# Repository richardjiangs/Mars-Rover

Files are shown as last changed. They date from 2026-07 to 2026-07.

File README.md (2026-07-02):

# PROJECT ARES — 低成本火星车原型 (Operation MROS)

一辆 150 美元以内的六轮火星车模型：`ESP32 NodeMCU + ESP32-CAM` 双脑架构、`Rocker-Bogie` 摇臂-转向架悬挂、3D 打印四层主舱、可承受 2 米跌落，能自动驾驶、拍 360° 全景与伪 3D 照片、绘制区域地图，并支持电脑端实时监控与人工接管。

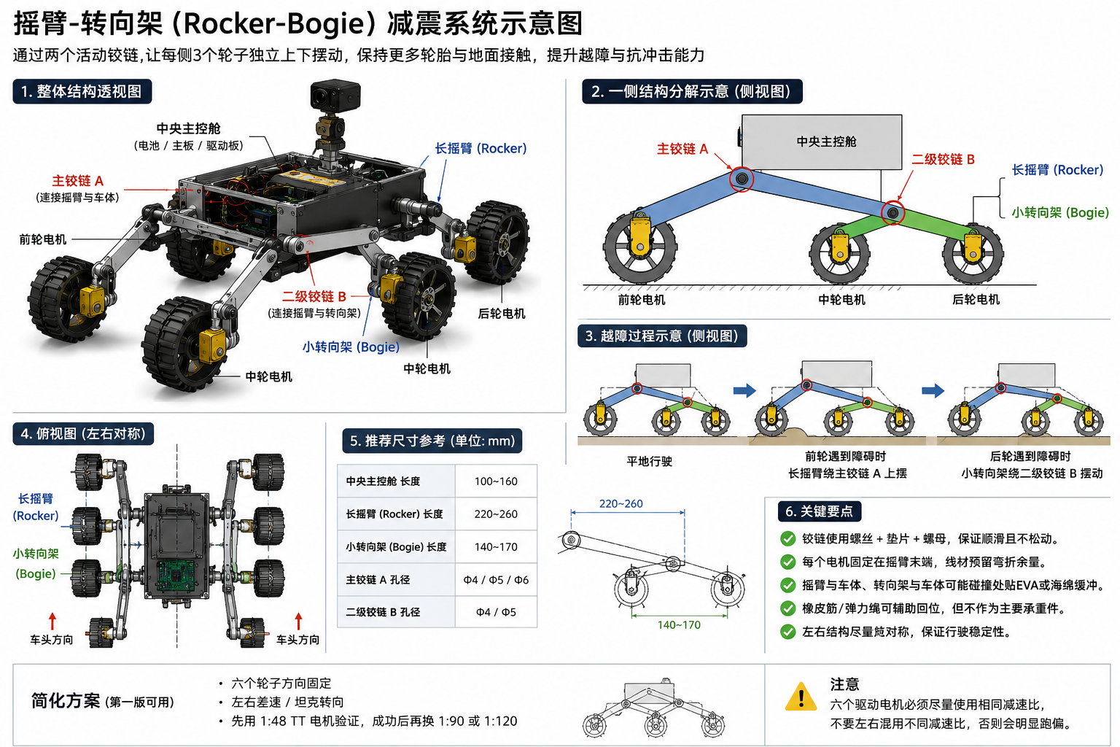
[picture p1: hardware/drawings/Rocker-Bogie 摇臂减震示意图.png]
Rocker-Bogie 示意


## 当前状态

- ✅ 设计定稿（V3 基线：见 `AGENTS.md` 与 `docs/Ares_V3_决策记录.md`）
- ✅ 硬件已采购（`hardware/drawings/部件.jpg`）、结构件已建模（`hardware/cad/`）
- ✅ 固件、网页控制台、电脑端图像处理脚本已编写
- ⏳ 待完成：3D 打印、补采购、装配、烧录、标定与验收测试 → 见 `docs/下一步你要做什么.md`

## 目录导航

| 目录 | 内容 |
| --- | --- |
| `docs/` | 设计文档、决策记录、装配与测试指南、行动清单 |
| `hardware/` | 引脚表（★`Ares_V3_GPIO_Map.md`）、BOM、接线资料、手绘图纸、STL |
| `firmware/commander/` | 主控 ESP32 固件（Arduino IDE 工程） |
| `firmware/cam/` | ESP32-CAM 固件（Arduino IDE 工程） |
| `dashboard/` | 网页控制台（浏览器直接打开 `index.html`） |
| `vision/` | 电脑端 Python：收图服务、全景拼接、红蓝 3D、地图、遥测记录、模拟器 |

## 三条上手路径

**① 我想了解设计** → 依次读 `AGENTS.md` → `docs/楼层布局.md` → `hardware/drawings/总体设计.jpg` → `docs/Ares_Control_Architecture.md`。

**② 我要造车** → 按 `docs/下一步你要做什么.md` 打印/采购/装配，装配细节见 `docs/装配与测试指南.md`，接线唯一以 `hardware/Ares_V3_GPIO_Map.md` 为准。

**③ 我要跑软件（可以完全不接硬件先试）**

```bash
# 1. 安装电脑端依赖
cd vision && pip install -r requirements.txt

# 2. 启动"假火星车"模拟器
python mock_rover.py

# 3. 浏览器打开 dashboard/index.html，
#    车辆地址填 127.0.0.1 后点"连接"，即可看到遥测并用 WASD 遥控
```

有硬件后：按 `firmware/commander/README.md` 与 `firmware/cam/README.md` 烧录两块板，dashboard 里把地址换成火星车真实 IP。

## 安全提醒

18650 电池必须经 2S BMS，充电只用 2S 专用充电器；HC-SR04 的 Echo 引脚需 1k/2k 分压后再接 ESP32；调试电机先把车架空。完整底线见 `AGENTS.md` 的"安全与工程底线"。

## License

Apache-2.0（见 `LICENSE`）。

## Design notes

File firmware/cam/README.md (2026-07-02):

# ESP32-CAM 视觉从板固件（AI-Thinker）

拍照 → HTTP 上传到电脑 `vision/receive_server.py`；提供 `/stream` MJPEG 实时流给 dashboard；通过串口应答 Commander 的拍照命令。协议见 `docs/Ares_Control_Architecture.md` §11.2。

**无需安装第三方库**（相机驱动、WebServer、HTTPClient 都在 ESP32 核心包里）。

## 烧录（用你买的下载器底板最省事）

1. 把 ESP32-CAM 插到 **下载器底板** 上，USB 连电脑。
   （没有底板的话：用 USB-TTL，5V/GND/U0R↔TX/U0T↔RX，且把 `GPIO0 接 GND` 进入烧录模式。）
2. ⚠ **如果板子已装上车：先断开与 Commander GPIO25/23 相连的两根串口线**，否则烧录会失败。
3. Arduino IDE 打开本目录（`cam.ino`），改 `config.h`：
   - `WIFI_SSID / WIFI_PASSWORD`：与 Commander 同一网络；
   - `PC_HOST`：电脑在该网络中的 IP（Windows 移动热点通常是 `192.168.137.1`）。
4. 开发板选 **AI Thinker ESP32-CAM**，点上传。
   （若列表里没有，选 ESP32 Dev Module 并把 PSRAM 设为 Enabled 也可。）
5. 上传完 **把 GPIO0 从 GND 断开**（用底板则拨开关/直接拔插），按 RST 重启。

## 自检

1. 串口监视器（115200）看 `# ip 192.168.x.x` —— 这是相机 IP。
2. 浏览器开 `http://<相机IP>/stream` 应看到实时画面。
3. 电脑先跑 `python vision/receive_server.py`，再访问 `http://<相机IP>/capture?name=test`，
   `vision/incoming/test.jpg` 出现即链路全通。
4. 装上车接回串口线后，Commander 遥测里 `cam` 字段应变为 `READY`。

## 板载指示灯

- 红色小灯（GPIO33）：常亮=启动中，闪烁=连 Wi-Fi，灭=就绪。
- 白色大灯（GPIO4）：默认不用；`config.h` 里 `USE_FLASH_LED 1` 可作拍照补光（耗电）。

## 已知限制

- 与 Commander 的链路复用烧录串口 U0：调试输出以 `# ` 开头，Commander 会忽略；但**烧录/看串口时必须断开车内串口线**。
- MJPEG 直播和拍照上传共用同一颗摄像头，直播中拍照会让画面停顿约 1 秒，正常现象。

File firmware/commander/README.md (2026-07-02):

# Commander 主控固件（ESP32 NodeMCU）

主控板固件：电机差速、直线保持、三向避障、模式状态机、休眠模拟、指挥相机板、WebSocket 遥测遥控。引脚与 `hardware/Ares_V3_GPIO_Map.md` 一致。

## 一、准备 Arduino IDE（一次性）

1. 安装 [Arduino IDE 2.x](https://www.arduino.cc/en/software)。
2. `文件 → 首选项 → 其他开发板管理器地址` 填入：
   `https://espressif.github.io/arduino-esp32/package_esp32_index.json`
3. `工具 → 开发板 → 开发板管理器` 搜索 `esp32`，安装 **esp32 by Espressif Systems**（2.x 或 3.x 均可，本固件已做兼容）。
4. `工具 → 管理库` 安装两个库：
   - **ArduinoJson**（Benoit Blanchon，版本 ≥ 7.0）
   - **WebSockets**（Markus Sattler / links2004，版本 ≥ 2.4）
5. 可选件启用时才需要的库：
   - `ENABLE_DS18B20 1` → 再装 **OneWire** 和 **DallasTemperature**

## 二、烧录

1. 用 Arduino IDE 打开本目录（`commander.ino`）。
2. 修改 `config.h` 顶部的 `WIFI_SSID` / `WIFI_PASSWORD`（建议用电脑开热点，见 `docs/Ares_Control_Architecture.md` §6.1）。
3. 开发板选 **ESP32 Dev Module**，默认参数即可；插 USB 选对串口。
4. 点上传。若一直 `Connecting...`，按住板上 `BOOT` 键再点上传。
5. 打开串口监视器（115200），会看到 IMU 标定提示和 **WiFi IP 地址**——dashboard 里要填这个 IP。

## 三、首次上电自检顺序（务必架空车轮！）

1. 上电后 2 秒内不要动车（IMU 零偏标定）。
2. 串口出现 `ready.` 后，浏览器打开 `dashboard/index.html`，填 IP → 连接。
3. 依次验证：遥测数字在跳 → E-STOP 按下电机锁死 → TELEOP 下 WASD 车轮转向正确 → AUTO 下手挡超声波会触发停车转向。
4. 车轮转向不对：对调该侧电机接线，或在 `config.h` 里交换该侧 FWD/REV 引脚号。

## 四、config.h 里最常改的参数

| 参数 | 何时改 |
| --- | --- |
| `WIFI_SSID/PASSWORD` | 必改 |
| `PIN_SONAR_*` | 装车后发现 F/L/R 对不上时对调 |
| `PIN_I2C_SDA/SCL` | MPU6050 初始化失败时互换（手绘图与标准相反） |
| `YAW_KP/KD` | T2 直线测试跑偏时调（先 P 后 D，见测试指南） |
| `CM_PER_SEC_CRUISE` | T2 实测速度后回填（影响伪 3D 的 6cm 前进精度） |
| `ENABLE_LDR/DS18B20/VBAT` | 对应可选件装上后置 1 |
| `MOTOR_MAX_PCT` | 单 L298N 过热时调低 |

## 五、与其他部分的接口

- **对 dashboard**：WebSocket `ws://<板子IP>:81`，JSON 协议见 `docs/Ares_Control_Architecture.md` §11.1。
- **对 ESP32-CAM**：UART2（TX=GPIO25→CAM GPIO3，RX=GPIO23←CAM GPIO1），ASCII 行协议见 §11.2。烧录 CAM 时先拔掉这两根线。
- **单独调试底盘**：把 `config.h` 的 `ENABLE_CAMLINK` 置 0，可在不接相机板时消除 CAM_TIMEOUT 告警。

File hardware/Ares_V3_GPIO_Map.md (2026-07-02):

# Ares V3 GPIO Map（全车唯一权威引脚表）

> 本表取代散佚的 `⭐Ares Dual-Brain GPIO Map.docx`，并按 V3 基线（`hardware/drawings/线路图.jpg` 手绘接线）重建。
> 引脚改动必须先改本表，再同步 `firmware/commander/config.h` 与 `firmware/cam/config.h`。
> 来源标注：【手绘】= 线路图.jpg 明确画出；【V2.2】= 沿用旧 Wiring Chart；【推断】= 为落地补齐的工程推断；【待确认】= 需要实物验证或用户拍板。

## 1. Commander ESP32（NodeMCU 38pin）

### 1.1 电机驱动（L298N）

| 功能 | ESP32 GPIO | L298N 引脚 | 来源 |
| --- | --- | --- | --- |
| 左侧 3 电机 正转 | GPIO 16 | IN1 | 【手绘】"左正D16" |
| 左侧 3 电机 反转 | GPIO 17 | IN2 | 【手绘】"左反D17" |
| 右侧 3 电机 正转 | GPIO 18 | IN3 | 【手绘】"右正D18" |
| 右侧 3 电机 反转 | GPIO 19 | IN4 | 【手绘】"右反D19" |

- 调速方式：固件直接在 IN1–IN4 上输出 LEDC PWM（正转脚给占空比、反转脚拉低），不占用 ENA/ENB。ENA/ENB 保持跳线帽常使能。【推断，依据 `docs/Ares_Control_Architecture.md` §9.3】
- L298N `+12V` 接 7.4V 总线，`GND` 接共地，板上 5V 稳压跳线保持默认（不从 L298N 取 5V 给逻辑板）。【手绘】

⚠️ **单 L298N 电流风险**：每通道并联 3 个 TT 电机，堵转时总电流可能达 3–6A，超过 L298N 单通道约 2A 的持续能力。缓解措施：
1. 固件内置软启动斜坡（默认 ≤ 每 20ms 增加 5% 占空比）和最高占空比限幅；
2. 避免长时间堵转（避障逻辑遇阻即停）；
3. 若实测驱动板过热/掉电，升级为双 L298N：左组接第 1 块的 IN1/IN2+OUT1/OUT2，右组接第 2 块的 IN3/IN4+OUT3/OUT4，**固件引脚完全不变**。【待确认：实车电流实测】

### 1.2 超声波（3 × HC-SR04，独立三向 = AUTO-L2）

| 位置 | Trig | Echo | 来源 |
| --- | --- | --- | --- |
| 前方 Front | GPIO 13 | GPIO 14 | 【手绘】D13/D14 一组 |
| 左前 Front-Left | GPIO 27 | GPIO 26 | 【手绘】D27/D26 一组 |
| 右前 Front-Right | GPIO 33 | GPIO 32 | 【手绘】D33/D32 一组 |

- 手绘图能确认三组引脚配对，但**哪组对应哪只探头未标注**，以上 F/L/R 分配为【推断】，装车后如不符只需改 `config.h`，不必改线。
- ⚠️ **Echo 是 5V 输出，必须分压**：每路 Echo 串 1kΩ 后对 GND 接 2kΩ，从分压点接 ESP32（3.3V ≈ 5V × 2/3）。HC-SR04 的 VCC 仍接 5V 总线。【推断，安全底线】
- 三路轮询测距（间隔 ≥ 30ms），防止互相串扰。【推断】

### 1.3 I2C（MPU6050）

| 功能 | ESP32 GPIO | MPU6050 | 来源 |
| --- | --- | --- | --- |
| SDA | GPIO 21 | SDA | 【V2.2/ESP32 标准】 |
| SCL | GPIO 22 | SCL | 【V2.2/ESP32 标准】 |

- ⚠️ 手绘图标注为 `SCL–D21、SDA–D22`，与 ESP32 标准（SDA=21/SCL=22）**相反**。固件默认按标准；若实物按手绘接了线，改 `config.h` 的 `PIN_I2C_SDA/PIN_I2C_SCL` 两个常量即可，无需改线。【待确认：以实物接线为准】
- MPU6050 VCC 接 3V3（模块带稳压时接 5V 也可，手绘接 3V3），必须水平安装、线长 < 10cm、紧贴洞洞板刚性固定。【手绘】

### 1.4 云台舵机与相机链路

| 功能 | ESP32 GPIO | 对端 | 来源 |
| --- | --- | --- | --- |
| 云台 SG90 PWM | GPIO 4 | SG90 橙线 | 【V2.2 沿用；手绘缺失但任务需要】 |
| UART2 TX | GPIO 25 | ESP32-CAM GPIO 3 (U0RXD) | 【推断：V2.2 的 16/17 已被电机占用，重映射】 |
| UART2 RX | GPIO 23 | ESP32-CAM GPIO 1 (U0TXD) | 【推断，同上】 |

- UART2 参数：115200 8N1，ASCII 行协议（见 `docs/Ares_Control_Architecture.md` §11.2）。
- SG90 电源接 5V 总线；6 只舵机中仅 1 只入基线（云台），折叠翼舵机随太阳能取消。【V3】

### 1.5 可选传感器（基线预留，未购/未接不影响运行）

| 功能 | ESP32 GPIO | 说明 | 来源 |
| --- | --- | --- | --- |
| LDR 模拟量 AO | GPIO 34（输入专用，ADC1_CH6） | 光强读数，判断昼/夜 | 【推断】 |
| LDR 数字量 DO | GPIO 35（输入专用，RTC GPIO） | 深度休眠 ext0 唤醒源 | 【推断】 |
| DS18B20 DATA | GPIO 15 + 4.7kΩ 上拉到 3V3 | 舱内温度；V2.2 的 GPIO27 已被超声波占用 | 【推断】 |
| 电池电压检测 | GPIO 36（输入专用，ADC1_CH0） | 7.4V 经 100kΩ/33kΩ 分压 ≈ 满电 2.1V | 【推断：遥测 battery_v 需要；不接则遥测报 0】 |

### 1.6 Commander 电源

| 引脚 | 接法 | 来源 |
| --- | --- | --- |
| VIN | 5V 总线（LM2596 OUT+） | 【手绘】 |
| GND | 共地总线 | 【手绘】 |

### 1.7 引脚占用一览（Commander）

```
已用   : 4(舵机) 13,14(超声F) 16,17,18,19(电机) 21,22(I2C) 23,25(UART2) 26,27(超声L) 32,33(超声R)
可选   : 15(DS18B20) 34,35(LDR) 36(电压检测)
保持空 : 0,2,5,12(启动选通脚，避免上电电平干扰) 1,3(USB 串口) 39(备用ADC)
```

## 2. ESP32-CAM（AI-Thinker）

| 功能 | 引脚 | 说明 |
| --- | --- | --- |
| 5V / GND | 5V 总线 / 共地 | 【手绘】直接 5V 供电更稳（3V3 供电易复位） |
| U0TXD (GPIO 1) | → Commander GPIO 23 | UART 从协议上行 |
| U0RXD (GPIO 3) | ← Commander GPIO 25 | UART 从协议下行 |
| GPIO 0 | 烧录时接 GND，运行时悬空 | 烧录模式选择 |
| GPIO 4 | 板载闪光灯 LED（固件可用作拍照补光） | 板内固定 |
| GPIO 33 | 板载红色状态灯（低电平点亮） | 板内固定 |
| 摄像头排线各脚 | AI-Thinker 标准分配 | 见 `firmware/cam/camera_pins.h` |

⚠️ CAM 用 U0（烧录串口）兼作与主控的链路：**烧录/接串口监视器前必须先断开与 Commander GPIO25/23 的两根线**，否则烧录失败。运行时再接回。【推断，需实机遵守】

## 3. 供电拓扑（V3）

```
2×18650(7.4V) → 2S BMS(B+/B-) → P+/P- → 船型/钮子总开关 → [7.4V 总线]
[7.4V 总线] → L298N +12V             （电机动力）
[7.4V 总线] → LM2596 IN+ → OUT+ 调至 5.00V → [5V 总线]
[5V 总线]  → ESP32 VIN、ESP32-CAM 5V、HC-SR04×3 VCC、SG90、（LDR 模块）
[GND]      → 全系统共地（BMS P-、LM2596、L298N、两块板、所有传感器）
充电：取出电池用 2S 专用充电器，或经 BMS 的充电口用 8.4V CC/CV 适配器（太阳能已取消）
```

## 4. 与 V2.2 Wiring Chart 的差异速查

| 项目 | V2.2（hardware/Ares_Master_Wiring_Chart.md） | V3（本表，现行） |
| --- | --- | --- |
| 电机引脚 | 32/33/25/26，双 L298N | 16/17/18/19，单 L298N（双板可选） |
| 超声波 | 3 只并联在 19/18 | 3 只独立：13/14、27/26、33/32 |
| UART2↔CAM | 16(RX2)/17(TX2) | 25(TX2)/23(RX2) |
| 太阳能板+翼舵机 | 3 块板 + GPIO 13/12 舵机 | 已取消 |
| DS18B20 | GPIO 27 | GPIO 15（可选） |
| 云台舵机 | GPIO 4 | GPIO 4（不变） |
| MPU6050 | 21/22 | 21/22（不变，注意手绘标反） |

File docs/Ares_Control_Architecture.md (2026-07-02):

# Ares 自动驾驶与电脑接管控制架构草案

## 1. 文档目标

本文档用于明确 `PROJECT ARES / Operation MROS` 在当前原型阶段的控制架构，目标是同时满足以下两类能力：

- 火星车可以在本地传感器支持下执行基础自动驾驶。
- 操作者仍然可以在电脑端实时查看状态，并在需要时手动接管控制。

本文档默认延续仓库现有的 `双脑架构`，不直接照搬 `OpenRover` 的整套电控平台，只吸收其轮组、驱动系统布局和机械臂扩展思路。

## 2. 依据文档

本草案主要依据以下仓库资料：

- `output/doc/⭐火星车原型制作完整指南.md`
- `output/doc/⭐火星车主采购清单(中文版) STAR.md`
- `output/doc/⭐Ares Master Wiring Chart.md`
- `⭐Ares Dual-Brain GPIO Map.docx`

## 3. 现有基线与文档明确内容

以下内容属于现有文档中已经明确给出的基线：

- 整车采用 `ESP32 NodeMCU + ESP32-CAM` 双脑架构。
- 主控 `ESP32` 负责电机控制、超声波、`MPU6050`、休眠唤醒、舵机动作和对相机板发指令。
- `ESP32-CAM` 负责拍照、图像回传，以及必要的串口确认。
- 底盘默认是六轮方案，左右各 3 个 TT 电机并联，由两块 `L298N` 分别驱动。
- 主控与相机板之间通过串口交叉连接：
  - `Commander GPIO 16 (RX2) <- ESP32-CAM TX`
  - `Commander GPIO 17 (TX2) -> ESP32-CAM RX`
- 当前 `Wiring Chart` 中的关键主控引脚分配如下：
  - 左驱动：`GPIO 32`、`GPIO 33`
  - 右驱动：`GPIO 25`、`GPIO 26`
  - `MPU6050`：`GPIO 21/22`
  - 超声波：`GPIO 19/18`
  - 扫描舵机：`GPIO 4`
  - 左右太阳能翼舵机：`GPIO 13/12`

## 4. 已知文档冲突与本草案处理方式

### 4.1 充电方案冲突

- `完整指南` 提到 `TP4056`。
- `采购清单` 与 `Wiring Chart` 明确围绕 `2S BMS + 2x18650 串联 + 7.4V` 工作。

本草案默认采用 `2S BMS` 方案，因为它与双节串联电池和整车电压等级更一致，也更符合当前仓库的安全基线。

### 4.2 超声波方案冲突

- `完整指南` 倾向于 `前 / 左前 / 右前` 三个独立 HC-SR04。
- `Wiring Chart` 把 3 个 HC-SR04 并到同一组 `Trig/Echo`，等效为一个“总前保险杠”。

本草案给出两级实现路线：

- `AUTO-L1`：兼容当前 `Wiring Chart`，按“并联单前向感知”实现基础自动避障。
- `AUTO-L2`：推荐升级为“独立三向感知”，这样自动驾驶才具备更可靠的选路能力。

也就是说，本文不会静默混用两种方案，而是把它们明确区分为“当前兼容实现”和“推荐升级实现”。

## 5. 与 OpenRover 的参考边界

`OpenRover robotic platform` 适合作为以下方面的参考：

- 轮组、车轮安装方式和更稳健的电机机械布局。
- 机械臂的结构思路、挂载位置和电脑端联动操作体验。
- 人机界面层面的“监控 + 手动接管”设计思路。

但 `Ares` 当前阶段不建议直接照搬 `OpenRover` 的整套多板控制结构。原因如下：

- 当前仓库已经明确了 `ESP32 主控 + ESP32-CAM` 的双脑基线。
- 项目有明显的低成本约束，不适合直接引入更多上位板卡。
- 当前任务重点是先把“能自动跑，也能从电脑接管”做通，而不是先把整车做成复杂多处理器平台。

因此，本草案采用“借机械，不借全套电控”的策略。

## 6. 推荐系统架构

```mermaid
flowchart LR
    PC["电脑端控制台<br/>Dashboard / Teleop / 图像处理"] -->|Wi-Fi: 指令 / 心跳 / 遥测| CMD["Commander ESP32"]
    CAM["ESP32-CAM"] -->|Wi-Fi: 视频流 / 图片文件| PC
    CMD -->|UART2| CAM
    CMD --> MOTOR["L298N x2 + 左右 6 轮驱动"]
    CMD --> SENSOR["MPU6050 + HC-SR04 + LDR + 舵机"]
    BAT["2S Battery + 2S BMS + LM2596"] --> CMD
    BAT --> CAM
    BAT --> MOTOR
```

### 6.1 推荐网络拓扑

为了同时满足电脑控制和相机图传，推荐以下网络方式：

- 电脑开启热点，作为整车调试阶段的临时局域网中心。
- `Commander ESP32` 接入该热点，提供控制接口和遥测接口。
- `ESP32-CAM` 也接入同一热点，直接向电脑提供视频流或图片上传。

这样做的好处是：

- 电脑可以直接控制主控板。
- 电脑可以直接接收相机流，不必让主控转发图像。
- 主控与相机板仍保留 `UART` 控制链路，用于可靠的任务级命令和确认。

## 7. 子系统职责划分

### 7.1 Commander ESP32

`Commander` 是底盘运动的唯一仲裁者，负责：

- 左右电机启停、方向与速度控制。
- `MPU6050` 姿态修正与直线保持。
- 超声波避障逻辑。
- `AUTO / TELEOP-PC / E-STOP / IDLE` 模式切换。
- 舵机控制，包括扫描舵机和未来可能扩展的机械臂互锁。
- 向 `ESP32-CAM` 下发拍照、扫描、状态查询命令。
- 向电脑端回传整车遥测。

### 7.2 ESP32-CAM

`ESP32-CAM` 是视觉从板，负责：

- 拍照。
- 360 度扫描过程中的图像采集。
- 伪 3D 拍摄任务中的图像采集确认。
- 通过 Wi-Fi 向电脑端提供实时画面或文件上传。
- 通过 UART 向主控回传 `ACK / BUSY / DONE / ERROR`。

### 7.3 电脑端

电脑端不是底盘运动执行器，而是“操作与后处理中心”，负责：

- 实时显示遥测、模式、报警和连接状态。
- 手动驾驶输入。
- 下发模式切换命令。
- 查看视频流和拍摄结果。
- 做全景拼接、伪 3D 合成、地图后处理。
- 在需要时强制人工接管，或发送 `E-STOP`。

## 8. 控制模式与优先级

### 8.1 模式定义

| 模式 | 作用 | 谁发起 | 底盘动作权限 |
| --- | --- | --- | --- |
| `IDLE` | 上电待命 / 任务前静止状态 | 系统默认 | 禁止移动，仅保留监测 |
| `AUTO` | 基础自动驾驶 | 电脑或本地任务逻辑 | 主控本地闭环控制 |
| `TELEOP-PC` | 电脑端人工驾驶接管 | 电脑端 | 电脑发指令，主控执行 |
| `CAPTURE` | 原地或低速执行拍摄动作 | 主控任务逻辑 | 受任务脚本限制 |
| `E-STOP` | 紧急停车 | 电脑端或本地故障逻辑 | 全部驱动立即停机 |
| `SLEEP` | 低功耗休眠 | 主控任务逻辑 | 电机关闭 |

### 8.2 优先级

模式优先级按以下顺序处理：

1. `E-STOP`
2. 硬件故障 / 欠压保护
3. `TELEOP-PC`
4. `AUTO`
5. `CAPTURE`
6. `IDLE`
7. `SLEEP`

说明：

- 只要收到有效 `E-STOP`，必须立即切断运动输出。
- 只要操作者在 `AUTO` 模式下发出有效人工驾驶指令，系统应切入 `TELEOP-PC`。
- 如果电脑端在 `TELEOP-PC` 模式下心跳丢失，整车不应继续盲目前进，而应转入 `IDLE` 或 `E-STOP`。

### 8.3 推荐状态机

```mermaid
stateDiagram-v2
    [*] --> IDLE
    IDLE --> AUTO: set_mode(AUTO)
    IDLE --> TELEOP: set_mode(TELEOP-PC)
    IDLE --> SLEEP: light_low / schedule_sleep
    AUTO --> TELEOP: operator_override
    AUTO --> CAPTURE: mission_capture_step
    AUTO --> E_STOP: fault / estop
    TELEOP --> IDLE: release_control
    TELEOP --> E_STOP: estop / heartbeat_timeout
    CAPTURE --> AUTO: capture_done
    CAPTURE --> TELEOP: operator_override
    SLEEP --> IDLE: wake_by_light / wake_by_timer
    E_STOP --> IDLE: clear_fault + manual_ack
```

## 9. 自动驾驶能力建议

### 9.1 AUTO-L1：兼容当前接线图的基础自动驾驶

如果保留当前 `Wiring Chart` 的“3 个 HC-SR04 并联到同一组 `Trig/Echo`”，则自动驾驶能力建议定义为：

- `MPU6050` 做直线保持。
- 前方检测到障碍时立刻停车。
- 采用预设回避动作，例如：
  - 后退固定时长；
  - 原地左转固定角度；
  - 再次试探前进。

这种模式可以实现“基础自动跑”，但其本质更接近“前向碰撞规避”，而不是高质量选路自动驾驶。

### 9.2 AUTO-L2：推荐的三向感知自动驾驶

如果为了更像真正的自动驾驶，建议将超声波升级为独立三向感知：

- `Front` 用于正前避障。
- `Front-Left` 与 `Front-Right` 用于比较左右通行空间。
- 当前方距离低于阈值时，主控读取左右距离，选择更大侧转向。

这一路线更符合 `完整指南` 中“前 / 左前 / 右前”三探头寻路逻辑，也更适合你后续做地图和任务路径记录。

### 9.3 直线保持

无论使用 `AUTO-L1` 还是 `AUTO-L2`，都建议保持以下闭环：

- `目标航向` 在每次直行段开始时锁定。
- `MPU6050` 实时给出偏航变化。
- 主控根据偏差对左右轮组做小幅差速修正。

这里有一个工程提醒：

- 当前接线图只给出了 `L298N` 的方向控制口，没有单独展开 `ENA/ENB` 速度使能口。
- 如果继续沿用当前接线，速度调节可以通过对方向输入脚输出 `PWM` 来实现。
- 如果后续发现调速效果不足，再考虑把 `ENA/ENB` 也纳入正式引脚表。

## 10. 电脑端人工接管设计

### 10.1 设计原则

- 电脑端负责“下达意图”，主控负责“安全执行”。
- 电脑端不直接绕过主控去控制电机驱动器。
- 所有人工控制都必须经过主控的安全仲裁。

### 10.2 推荐交互

电脑端建议提供以下界面元素：

- 视频窗口。
- 模式切换按钮：`AUTO`、`TELEOP-PC`、`IDLE`、`E-STOP`。
- 虚拟摇杆或键盘控制。
- 实时遥测显示：电压、当前模式、障碍距离、姿态角、相机状态。
- 任务按钮：`开始全景拍摄`、`开始伪 3D 拍摄`、`停止任务`。

### 10.3 人工接管规则

- 在 `AUTO` 模式下，只要电脑端持续发送非零速度指令并保持心跳，系统切换为 `TELEOP-PC`。
- 在 `TELEOP-PC` 模式下，若心跳超过超时阈值未更新，主控立即停车。
- 人工接管结束后，不自动恢复 `AUTO`，应由操作者显式点击恢复，避免误恢复。

## 11. 通信接口建议

### 11.1 电脑 <-> Commander

推荐使用 `Wi-Fi + WebSocket`，原因是：

- 能双向实时通信。
- 适合遥测高频回传。
- 适合浏览器或桌面上位机同时使用。

推荐消息格式使用轻量 JSON。

#### 电脑端下行命令示例

```json
{"type":"heartbeat","ts":1712390400}
{"type":"set_mode","mode":"AUTO"}
{"type":"set_mode","mode":"TELEOP-PC"}
{"type":"drive","throttle":0.45,"turn":-0.20}
{"type":"task","name":"capture_panorama","step_deg":30}
{"type":"estop","active":true}
```

#### 主控上行遥测示例

```json
{"type":"telemetry","mode":"AUTO","battery_v":7.6,"yaw":2.3,"front_cm":34,"cam":"READY"}
{"type":"alert","level":"WARN","code":"HEARTBEAT_LOST"}
{"type":"task_state","name":"capture_panorama","state":"RUNNING","index":3}
```

### 11.2 Commander <-> ESP32-CAM

推荐继续沿用当前文档已经明确的 `UART2` 通道：

- `Commander GPIO 17 (TX2) -> ESP32-CAM RX`
- `Commander GPIO 16 (RX2) <- ESP32-CAM TX`

推荐使用简单的 ASCII 行协议，便于串口调试。

#### 主控下发示例

```text
PING
CAPTURE STILL pano_003
CAPTURE STILL stereo_left
CAPTURE STILL stereo_right
STREAM START
STREAM STOP
STATUS?
```

#### 相机板回传示例

```text
ACK PING
ACK CAPTURE pano_003
DONE CAPTURE pano_003
BUSY
ERR SD_WRITE_FAIL
STATUS READY
```

### 11.3 心跳机制

建议至少保留两类心跳：

- `PC -> Commander`：用于判断人工接管链路是否在线。
- `Commander -> ESP32-CAM`：用于判断相机从板是否存活。

## 12. 机械臂扩展建议

你提到可以参考 `OpenRover` 的机械臂，这个方向可以保留，但建议按“扩展载荷”处理，而不是并入当前最小可行原型基线。

### 12.1 建议边界

- 第一阶段先实现底盘自动驾驶与电脑接管。
- 机械臂作为第二阶段扩展。
- 机械臂动作默认只允许在 `TELEOP-PC` 或未来单独的 `MANIP` 模式下执行。

### 12.2 电气建议

- 机械臂不要直接挂在当前给逻辑板供电的 `5V BUS` 上。
- 若后续加入多自由度机械臂，建议新增独立 `Buck` 或独立舵机电源轨。
- 主控与机械臂之间必须做动作互锁，避免“高速行驶 + 大幅摆臂”导致翻车。

### 12.3 对现有目标的影响

引入机械臂会直接影响：

- 预算。
- 重心。
- 爬坡能力。
- 跌落抗性。
- 电池续航。

因此，机械臂应视为明确的架构增项，不应默认并入当前 `Ares` 基线 BOM。

## 13. 分阶段落地建议

### 阶段 1：先打通远程接管

- 电脑端能看到遥测。
- 电脑端能进入 `TELEOP-PC` 并控制底盘。
- `E-STOP` 可靠生效。

### 阶段 2：实现基础自动驾驶

- 主控完成 `MPU6050` 直线保持。
- 实现 `AUTO-L1` 的前向避障。
- 完成 `AUTO -> TELEOP-PC` 的人工接管切换。

### 阶段 3：接入拍摄任务

- 主控通过 UART 控制 `ESP32-CAM`。
- 完成全景拍摄任务状态流转。
- 完成伪 3D 两次拍摄触发与确认。

### 阶段 4：升级感知与扩展载荷

- 如果要提升自动驾驶质量，升级到独立三向 HC-SR04。
- 如果要引入 `OpenRover` 风格机械臂，再单独扩展控制模式和供电。

## 14. 待确认项

以下事项仍需要后续拍板：

- 自动驾驶是否正式采用 `AUTO-L2` 的三向独立超声波方案。
- `L298N` 调速是否满足直线修正要求，还是要把 `ENA/ENB` 正式纳入引脚表。
- 电脑端是优先做网页控制台，还是做桌面上位机。
- `ESP32-CAM` 图像上传是优先 MJPEG 视频流，还是优先拍照文件上传。
- 机械臂是否进入本期范围，还是留到第二阶段。

## 15. 结论

在当前仓库基线下，最稳妥的方案不是把 `Ares` 改成另一套完整平台，而是：

- 保持 `ESP32 主控 + ESP32-CAM` 双脑架构；
- 让主控成为运动与安全的唯一仲裁者；
- 让电脑端具备实时监控和人工接管能力；
- 让相机板专注视觉采集与图像回传；
- 把 `OpenRover` 的轮组、电机布局和机械臂思路作为“机械参考”和“第二阶段扩展”。

这条路线既保留了现有文档的一致性，也能直接支撑你提出的核心要求：`火星车可以自动驾驶，但我仍然能用电脑控制它。`

## 16. 机械减震与温度保护补充

### 16.1 Rocker-Bogie 机械减震

当前 `Ares` 原型不采用弹簧减震器，而采用被动连杆式 `Rocker-Bogie / 摇臂-转向架`：

- 每侧 3 个轮子由一根长摇臂和一根小转向架连接。
- 长摇臂通过主铰链连接中央车身，小转向架通过二级铰链连接长摇臂后端。
- 两个铰链都必须能自由转动，不能用热熔胶粘死。
- 主控舱、电池、驱动板尽量集中在中央车身，减少悬挂端重量。
- 电机线预留弯折余量，避免摇臂上下摆动时拉断线。

推荐第一版先固定六个轮子的朝向，用左右差速 / 坦克转向；不要一开始做全轮独立转向。

### 16.2 热控状态

增加以下温度保护状态，用于配合保温盒和可选温度传感器：

| 状态 | 触发条件 | 行为 |
| --- | --- | --- |
| `NORMAL` | 0°C ~ 45°C | 正常运行 |
| `COLD_START` | -10°C ~ 0°C | 低速短时运行，减少拍摄和电机负载 |
| `COLD_SLEEP` | < -10°C | 停止电机，进入低功耗等待 |
| `HOT_LIMIT` | 45°C ~ 50°C | 降低速度和拍摄频率 |
| `THERMAL_PAUSE` | > 50°C | 停车、停止拍摄、等待降温 |

主控遥测建议增加字段：

```json
{"type":"telemetry","mode":"AUTO","battery_v":7.6,"inside_temp_c":24.5,"thermal":"NORMAL"}
```

### 16.3 安全边界

- 基线方案只采用被动保温和温度监测，不默认加入主动加热片。
- 不允许裸电阻丝、无温控加热片直接贴近 18650 电池。
- 若未来加入主动加热，需要新增独立供电、保险丝、温控闭环和失效保护，不应直接挂在当前 `5V BUS` 或 `7.4V BUS` 上。

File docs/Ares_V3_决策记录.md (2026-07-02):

# Ares V3 决策记录（Decision Log）

> 记录两代设计（V2.2 文档系 vs V3 手绘系）冲突的裁决结果与理由。
> 每条标注：【文档确认】= 有仓库资料明确依据；【工程推断】= 为落地补齐；【待确认】= 需实物验证。
> 基线切换由用户于 2026-07 拍板：**以 V3 手绘最新版为项目基线**。

## D1. 项目基线 = V3 手绘版 【文档确认 + 用户拍板】

- 依据：`hardware/drawings/总体设计.jpg`、`hardware/drawings/线路图.jpg`、`docs/楼层布局.md`、`docs/2米高空坠落生存与自恢复方案.md`、`hardware/cad/*.stl` 相互吻合（主舱 190×149mm 与 主舱.stl 实测包络一致），且 `hardware/drawings/部件.jpg` 显示实际采购与 V3 一致（无太阳能板）。
- 结论：V2.2 文档（完整指南、BOM、Wiring Chart）降级为历史参考；冲突时 V3 优先。

## D2. 取消太阳能板，改外部充电 【文档确认】

- 依据：`docs/楼层布局.md` 天台层明确写"取消太阳能板：释放全部车顶空间"；部件照片无太阳能板；车顶空间让位于甲虫穹顶（跌落自翻正）。
- 影响：折叠翼舵机（V2.2 GPIO 13/12）取消；13 号脚改用于超声波；"100 天生存"演示改为：LDR（可选）+ 深度休眠 + RTC 唤醒计数模拟昼夜，充电由人工用 2S 充电器完成。
- 风险：无自主补能，长时演示需人工换电/充电。【待确认：演示时长安排】

## D3. 单块 L298N 驱动六电机 【文档确认 + 风险记录】

- 依据：线路图.jpg 只画一块 L298N（OUT1/2 左组、OUT3/4 右组）；部件照片只有一块驱动板。
- 风险：每通道 3 只 TT 电机并联，堵转电流可能超 L298N 单通道 ~2A 持续能力。
- 缓解：固件软启动斜坡 + 占空比限幅 + 遇障即停；实测过热则升级双 L298N（接法见 `hardware/Ares_V3_GPIO_Map.md` §1.1，固件引脚不变）。【待确认:T1 架空电流实测】

## D4. 超声波 = 3 只独立三向感知（AUTO-L2） 【文档确认】

- 依据：线路图.jpg 画了 3 组独立 Trig/Echo（13/14、27/26、33/32），与 `docs/Ares_Control_Architecture.md` §9.2 推荐的 AUTO-L2 一致，取代 V2.2 Wiring Chart 的并联方案（AUTO-L1）。
- F/L/R 与三组引脚的对应关系图中未标注，在 `firmware/commander/config.h` 中可调。【工程推断】
- Echo 必须 1k/2k 分压后接 ESP32。【工程推断，安全】

## D5. 电机引脚 = GPIO 16/17/18/19 【文档确认】

- 依据：线路图.jpg 标注"左正D16 左反D17 右正D18 右反D19"。
- 影响：V2.2 的 UART2（16/17）必须重映射 → 见 D7。

## D6. I2C 方向：代码按 SDA=21 / SCL=22 【工程推断，待确认】

- 冲突：线路图.jpg 写 `SCL–D21、SDA–D22`，与 ESP32 惯例（SDA=21/SCL=22）及 V2.2 Wiring Chart 相反。
- 裁决：固件默认 ESP32 标准方向；若实物按手绘接线导致 MPU6050 初始化失败，把 `config.h` 里 `PIN_I2C_SDA/PIN_I2C_SCL` 互换即可（免改线）。
- 附带约束（手绘明确）：I2C 线长 < 10cm、MPU6050 水平刚性固定在 F2 洞洞板上。

## D7. UART2↔CAM 重映射为 TX2=25 / RX2=23 【工程推断】

- 原因：V2.2 用的 16/17 已被电机占用（D5）；手绘图未画 UART 链路，但 `docs/Ares_Control_Architecture.md` §11.2 的任务级命令链路（PING/CAPTURE/ACK/DONE）需要它。
- CAM 侧复用 U0（GPIO1/3）：烧录 CAM 前必须断开这两根线。
- 备选：若 25/23 与后续扩展冲突，ESP32 UART 可映射到任意空闲脚，改 config 即可。

## D8. 充电保护 = 2S BMS，不用 TP4056 【文档确认，维持既有裁决】

- 依据：原 AGENTS.md、BOM、Wiring Chart 一致；TP4056 仅适用单节锂电池。

## D9. 云台舵机保留 GPIO 4 【工程推断】

- 手绘图没画舵机，但任务目标（360° 全景 = 舵机 0–180° 分步扫描）与已购 SG90 都需要它；V2.2 分配的 GPIO 4 在 V3 引脚表中无冲突，沿用。
- 360° 覆盖：舵机只有 180°，剩余角度靠车体原地自转 180° 后再扫一轮补齐。【工程推断，符合"用自身旋转代替 360° 相机"的任务描述】

## D10. LDR / DS18B20 / 电池电压检测 = 可选件 【工程推断】

- 部件照片中未见 LDR 模块与 DS18B20；固件按"可选"实现（config 开关，未接不影响运行）：
  - LDR：AO→GPIO34（光强遥测/休眠判据）、DO→GPIO35（深睡唤醒）；未接时休眠演示用定时器唤醒替代。
  - DS18B20：GPIO15；未接时热控状态机静默停用（thermal 遥测报 N/A）。
  - 电池电压：100k/33k 分压→GPIO36；未接时 battery_v 报 0。
- 建议补购（见 `docs/下一步你要做什么.md`）。

## D11. 机械臂 = 第二阶段扩展 【文档确认】

- 依据：`docs/Ares_Control_Architecture.md` §12：影响预算/重心/爬坡/跌落/续航，不进当前基线；结构可预留安装面。

## D12. 电脑端形态 = 网页控制台 + Python 脚本 【用户拍板】

- dashboard/index.html 直连 Commander WebSocket（遥测/遥控/E-STOP/任务），照片经 CAM→HTTP→`vision/receive_server.py`；拼接、3D、地图由 Python 离线处理。
- 固件工程形式 = Arduino IDE（用户拍板）；仓库组织 = 全面重组（用户拍板）。

## D13. 温度演示的安全边界 【文档确认，维持】

- 只做被动保温 + 温度监测 + 程序保护（五态机）；不加无温控加热片；不把锂电池放入冰箱/冷冻环境测试。

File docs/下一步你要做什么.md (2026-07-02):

# 下一步你要做什么（用户行动清单）

> 软件与文档我已全部备好；下面是只有你能做的实体部分，按顺序执行。
> 每一步的详细做法在括号里标注的文档中。

## ① 3D 打印（可以马上开始）

| 文件（hardware/cad/） | 份数 | 建议 |
| --- | --- | --- |
| 主舱.stl（190×149×75） | 1 | PETG/PLA+，壁 ≥3 圈，填充 25% |
| 顶盖.stl | 1 | 同上 |
| 楼层F1和F2.stl | 1 | 平放打印，填充 30% |
| 柱子.stl（桅杆，158 高） | 1 | 立打加 brim；能用 TPU 更抗摔 |
| 摆臂（需打印4份）.stl | **4** | **受力件：PETG，壁 4 圈，填充 ≥40%，平放打印** |
| 配重（50%+填充）.stl | 1 | **填充 ≥50%**（文件名即要求） |

## ② 补采购（部件照片里没有的东西）

必买：
- [ ] **65mm 越野软胎 ×6**（照片里没看到轮子；跌落方案要求空心/海绵大脚软胎，硬胎会折断电机轴）
- [ ] **2S 平衡充电器（8.4V）**（太阳能已取消，这是唯一充电手段）
- [ ] **M3 硅胶减震球 ×4+**（F2 主控板悬浮用，无人机飞控配件几块钱）
- [ ] **M3 尼龙铜柱套装（25/35mm）+ M4/M5 螺栓垫片防松螺母**（楼层支撑与铰链）
- [ ] **电阻：1kΩ×3 + 2kΩ×3**（三路超声波 Echo 分压，必须）
- [ ] **碳纤维细圆棒 2 根（或 PVC 扎带）**（甲虫穹顶）+ 高强度小弹簧或 TPU 件（桅杆底座）
- [ ] EVA 泡棉（含 5mm 高密度）、魔术贴绑带、22AWG 硅胶线、热缩管

可选（建议买，几块钱）：
- [ ] LDR 光敏模块（带 AO/DO）——休眠唤醒演示更真实（装上后 `config.h` 置 `ENABLE_LDR 1`）
- [ ] DS18B20 + 4.7kΩ——温度演示（`ENABLE_DS18B20 1`）
- [ ] 100kΩ + 33kΩ 电阻——电池电压遥测（`ENABLE_VBAT 1`）
- [ ] 红蓝 3D 眼镜——看伪 3D 成果

## ③ 今天就能做的软件试跑（不用任何硬件）

```bash
cd vision && pip install -r requirements.txt
python mock_rover.py
# 浏览器打开 dashboard/index.html → 地址 127.0.0.1 → 连接
# 玩：WASD 开车、切 AUTO 看自动避障、点任务按钮、按 E-STOP
```

## ④ 烧录两块板（件到齐前也能先做）

1. 装 Arduino IDE + ESP32 支持 + 2 个库（5 分钟，步骤：`firmware/commander/README.md` 第一节）。
2. 电脑开热点；两块板的 `config.h` 填热点名/密码；CAM 的 `PC_HOST` 填电脑 IP。
3. 烧 Commander（ESP32 Dev Module）→ 串口记下车 IP。
4. 烧 CAM（AI Thinker ESP32-CAM，用下载器底板；**若已接串口线先拔掉**）→ 记下相机 IP。
5. dashboard 填两个 IP，浏览器应看到遥测 + 画面。

## ⑤ 装配（打印件到手后）

按 `docs/装配与测试指南.md` 阶段 ①→④：先单侧摇臂 → 整车结构 → 四层主舱 → 接线（**LM2596 先调 5.00V，Echo 必须分压，全部共地**）。

## ⑥ 标定与逐级测试

按指南 T0→T8 顺序：架空联调 → 5m 直线（调 `YAW_KP`，把实测速度回填 `CM_PER_SEC_CRUISE` 和 plot_map 的 `--speed`）→ 避障 → 25° 坡 → 拍摄 → 休眠 → 建图 → **最后**才做 2m 跌落。

## ⑦ 遇到问题优先查

| 现象 | 先查 |
| --- | --- |
| 某侧车轮方向反 | 对调该侧电机线，或换 `config.h` 该侧 FWD/REV |
| MPU6050 初始化失败 | I2C 接反 → `config.h` 互换 SDA/SCL |
| 超声波 F/L/R 对不上 | `config.h` 对调三组 Trig/Echo 定义 |
| 遥测 cam 一直 OFF | 串口线 25/23 是否接、是否烧录后忘接回 |
| L298N 发烫/车没力 | 降 `MOTOR_MAX_PCT`；考虑换双 L298N（接法在 GPIO Map §1.1） |
| 直线跑偏 | 加大 `YAW_KP`；六电机减速比是否一致 |

## 完成后

11 项目标的验收总表在 `docs/装配与测试指南.md` 第四节——逐项打勾，就是你的结题材料。

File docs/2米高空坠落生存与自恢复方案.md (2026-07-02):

## 第一阶段：抗冲击与防震设计 (化解落地 G 力)

在接触地面的瞬间，火星车内部会产生巨大的剪切力。我们必须对之前确定的“三层碳纤维甲板”进行柔性升级。

### 1. 消除“碎城锤”效应 (电池隔离)

- **物理隐患：** 18650 电池是全车最重的部件。跌落时，如果它发生位移，会像攻城锤一样把旁边的线路和铜柱全部砸烂。
    
- **解决方案：** * 在负一楼（B1）的碳纤维底板上，先垫一层 **5mm 厚的高密度 EVA 泡棉**。
    
    - 将电池盒放在泡棉上，然后再用两根宽边魔术贴死死绑住。泡棉不仅防滑，还能在落地瞬间吸收电池巨大的向下惯性。

### 2. 神经中枢的“悬浮” 

- **物理隐患：** 刚性的 M3 尼龙铜柱在承受瞬间侧向冲击时极易被整齐切断。
    
- **解决方案：** 引入无人机飞控常用的 **“硅胶减震球（Rubber Dampers）”**。
    
    - 在一楼到二楼（主控板层）的连接处，不要用硬铜柱直接拧死。
        
    - 改用 4 个 M3 硅胶减震柱。这样 ESP32 主控板在物理上是“半悬浮”在硅胶上的。落地瞬间，硅胶的弹性形变会吃掉足以震碎芯片引脚的高频冲击波。

### 3. 最脆弱的死穴：TT 电机与车轮 

- **物理隐患：** TT 电机的白色塑料轴极其脆弱。如果 2 米跌落时是轮子先着地，杠杆力会瞬间折断电机轴或扫崩内部齿轮。
    
- **解决方案：**
    
    - **必须使用“超软空心海绵轮胎”：** 放弃硬质塑料轮毂的轮子。去淘宝购买外径 65mm 以上、内部是海绵填充或者空心的**大脚软胎**。
        
    - 软胎在这里扮演的是“着陆气囊”的角色。落地时，轮胎被极度压缩，用自身的形变换取电机轴的安全。

### 4. 视觉桅杆的“缩骨功”

- **物理隐患：** 顶部的 ESP32-CAM 和舵机如果硬挺挺地伸着，一旦倒栽葱落地，必定折断。
    
- **解决方案：**
    
    - 桅杆不能用铝管硬连。使用一段 **高强度的粗弹簧** 或者 **TPU (柔性 3D 打印材料)** 作为桅杆的底座。
        
    - 正常行驶时它能保持直立；一旦发生撞击或翻滚，它能像天线一样被压弯，冲击结束后再自动弹回。

## 第二阶段：防翻车与自恢复机制 

火星车在 2 米高空落下，在空中极易翻滚。如果没有太阳能板，我们正好可以利用车顶空间，做一个纯被动、零功耗的自复位系统。

### 核心解法：仿生学“甲虫穹顶” (Beetle-Dome Roll Cage)

这是排爆机器人最经典的设计。不要指望加装复杂的机械臂去把自己翻过来（太重且耗电），我们用纯几何学来解决问题。

- **结构设计：** * 在中央主舱盒子的顶部（天台层），用两根有弹性的 **碳纤维细圆棒** 或者 **PVC 扎带**，交叉成一个拱形的“X”状穹顶（就像雨伞的骨架或者甲虫的背部）。
    
    - 这个穹顶的最高点，必须**略高于**你的 ESP32-CAM 摄像头桅杆。
        
- **物理自恢复逻辑 (重心偏移原理)：**
    
    1. 之前我们将最重的电池放在了负一楼，整车的 **重心 (Center of Gravity, CG) 极低**。
        
    2. 如果火星车不幸“底盘朝天”落地，它会以那个半圆形的“甲虫穹顶”接触地面。
        
    3. 由于背面是圆弧形，且全车 70% 的重量（电池和电机）都在“上方”（此时因为翻车了，底盘在上面），处于**极度不稳定的头重脚轻状态**。
        
    4. 只需要地面的一点点倾斜，或者内部 MPU6050 检测到翻车后让电机猛转一下（利用轮子的旋转惯性），甚至只靠重力本身，圆弧形的穹顶就会自动向一侧滚动。
        
    5. 由于重心极低，它滚到侧面后会自然而然地翻正，6 个轮子重新稳稳落地。

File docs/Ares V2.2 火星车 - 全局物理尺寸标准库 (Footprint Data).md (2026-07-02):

工程单位声明： 3D 建模与 CNC 加工必须统一使用毫米 (mm)。以下数据已将厘米全部转换为毫米标准单位。
1. 能源与动力核心 (Power & Drive)
    1. 双节 18650 电池盒： 75 × 40 × 20 mm特征： 全车最重、体积最大的单体部件。
    2. L298N 驱动板 (共 2 块)： 单块 43 × 43 × 27 mm特征： 带有高耸的金属散热片（高27mm），上方必须留出空间，绝对不能紧贴上一层板子，需防短路。
    3. LM2596 降压模块： 43 × 21 × 14 mm特征： 体积小巧，带有电位器旋钮，需要留出少量空间以便用螺丝刀调节5V电压。
    4. 大号钮子开关： 25 × 15 × 65 mm特征： 高度极其惊人（65mm），这根长长的金属拨杆在 2 米跌落时承受的杠杆剪切力极大，极易折断或误触。
2. 大脑与传感中枢 (Brain & Sensors)
    1. ESP32 主控 (含底座洞洞板)： 80 × 60 × 15 mm
        特征： 面积最大的一块逻辑板，直接决定了主控舱外壳的最小内部长宽（必须大于 80×60mm）。
    2. MPU6050 陀螺仪： 20 × 15 × 3 mm
        特征： 极薄。
    3. ESP32-CAM (带底板)： 40 × 27 × 15 mm
        特征： 需搭载在 SG90 舵机上旋转，不能有遮挡。
    4. HC-SR04 超声波雷达 (共 3 个)： 单个 45 × 20 × 18 mm
        特征： 必须并排或品字形安装在车头，面向正前方。
3. 底盘执行机构 (Chassis & Actuators)
    1. TT 直流减速电机 (共 6 个)： 单个 70 × 20 × 20 mm
    2. 越野车轮 (共 6 个)： 直径 65 mm，厚度约 26 mm

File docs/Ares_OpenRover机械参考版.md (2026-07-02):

# Operation MROS

## OpenRover 机械参考版说明

本版文档以 `⭐火星车原型制作完整指南.docx` / `output/doc/⭐火星车原型制作完整指南.md` 为底稿，仅替换以下三部分，其余内容保持原方案不变：

- 支架 / 中央机身固定方式
- 悬挂 / 车轮安装方式
- 机械臂结构

### 参考依据

- 仓库原始方案：`⭐火星车原型制作完整指南.docx`
- 当前 Markdown 转写：`output/doc/⭐火星车原型制作完整指南.md`
- OpenRover 公开资料：
  - `OpenRover robotic platform` README
  - `OpenRover` Hackaday 项目页

### 文档明确给出的保留项

以下内容本版不改：

- `ESP32 NodeMCU + ESP32-CAM` 双脑架构
- `6x TT motor + 2x L298N` 的基础驱动思路
- `MPU6050`、`HC-SR04`、`LDR`、`SG90` 的任务角色
- `3D / 360°` 拍摄逻辑

### 本版工程推断

OpenRover 的公开资料明确提到它是：

- `6-wheel drive platform with 4 steerable wheels`
- `4-axis foldable robotic arm with gripper`
- 机械平台通过 `3D printed parts + pvc tubes + aluminium profiles` 组装

但你当前 `Ares` 方案仍以低成本、双脑、`TT motor` 和现有接线为主，因此本版采用的是：

- 借鉴 OpenRover 的机械布局和安装方法
- 不直接照搬 OpenRover 的整套电控平台

也就是说，这是“机械借鉴版”，不是“整车架构替换版”。

IMPORTANT

## 🛒

为了实现复杂的功能，我们将采用“双脑”架构：一个ESP32负责控制和传感器，另一个ESP32-CAM专门负责图像处理和传输。

### 1. 核心大脑与视觉

- 1x ESP32 开发板 (NodeMCU): $6 (主控芯片，负责电机、超声波、陀螺仪、休眠逻辑)
- 1x ESP32-CAM 模块 (带OV2640摄像头): $7 (负责拍照、Wi-Fi图传)
- 1x SG90 微型舵机: $2 (用于搭载ESP32-CAM，实现360°旋转扫描)

### 2. 动力与底盘系统

- 6x TT 直流减速电机 + 配套越野轮胎: $15-$25 (V1 可先用便宜 1:48 验证结构；V2 推荐统一升级到 1:90，重车或强调爬坡可考虑 1:120)
- 2x L298N 电机驱动模块: $6 (一个控制左侧3个轮子，一个控制右侧3个轮子)
- 底盘支架与悬挂材料: $5-$15 (借鉴 OpenRover 的模块化机械思路，推荐使用 `3D 打印连接件 + PVC 管 / 铝型材 + 螺栓` 形成中央机身支架、左右摇臂和轮组安装座，而不是只用扎带和热熔胶把电机直接固定在悬挂末端)

### 3. 导航与避障传感器

- 3x HC-SR04 超声波传感器: $5 (分别安装在正前方、左前和右前，用于防撞和自动驾驶寻路)
- 1x MPU6050 陀螺仪/加速度计模块: $3 (极其重要：用于修正电机转速差，确保能在5米内走绝对直线)
- 1x 光敏电阻模块 (LDR): $1 (用于检测光照强度，决定是否唤醒火星车)

### 4. 能源与供电系统

- 1x 5V 小型太阳能电池板 (约130x150mm): $5 (安装在车顶)
- 1x 2S BMS 锂电池保护板: $2-$4 (用于 2 节 18650 串联电池的过充、过放和短路保护；TP4056 只适合单节锂电池，不作为本项目主方案)
- 2x 18650 锂电池 + 1x 双节电池盒: $10 (主电源)
- 1x LM2596 降压模块 (DC-DC): $3 (将电池的7.4V降压至5V，供ESP32和舵机使用)

### 5. 杂项与结构件

- 1 套中央机身支架 / 安装舱结构件: $5-$10 (借鉴 OpenRover 的中央模块化机身，建议用 `Project Box + 3D 打印支架 + 铝型材 / PVC 主管` 组成主支架，用于固定主控、电池、驱动板和相机桅杆)
- 1 套轻量机械臂结构件（可选）: $8-$20 (借鉴 OpenRover 的 `4-axis foldable robotic arm with gripper`，采用 3D 打印连杆、舵机支座和小夹爪，默认作为演示级扩展机构，不改变当前主控分工)
- 被动式岩石收集器: $0 (DIY：在车尾底部倾斜安装一个切开的硬塑料瓶或金属小铲，行驶时自然兜住小石块)
- 保温与热控材料: $3-$8 (EVA 泡棉、薄海绵、泡沫板、绝缘胶带、可选 DS18B20 温度传感器；用于实现 -20°~50°目标的保温与温度保护演示)
- 面包板、杜邦线 (公对公/公对母/母对母)、热熔胶枪、M3螺丝螺母、扎带、独立电源开关。

## 🛠️

### 步骤 1：搭建借鉴 OpenRover 的模块化 Rocker-Bogie 底盘与机械减震系统

本项目的“机械减震”不采用汽车弹簧减震器，而采用火星车常见的 `Rocker-Bogie / 摇臂-转向架`。它的核心不是“弹簧变软”，而是让每侧 3 个轮子通过两个活动铰链上下摆动，使轮子遇到障碍时车身不会被直接顶起。

#### 1.1 一侧三轮的结构

每一侧由一根长摇臂和一根小转向架组成：

```text
一侧侧视图：

                 中央车身盒 / 主控舱
             ┌────────────────────┐
             │ ESP32 / 电池 / 驱动 │
             └─────────O──────────┘
                       │ 主铰链 A
                       │
前轮电机+轮子  ○────────┘────────O  二级铰链 B
                                  │
                           中轮 ○─┴─○ 后轮
                              小转向架 Bogie
```

拆开看就是：

```text
长摇臂 Rocker：
前轮电机位 ───── 主铰链 A ───── 二级铰链 B

小转向架 Bogie：
中轮电机位 ───── 二级铰链 B ───── 后轮电机位
```

- 前轮压到障碍物时，长摇臂绕主铰链 A 转动。
- 中轮或后轮压到障碍物时，小转向架绕二级铰链 B 转动。
- 这样可以让六个轮子尽量保持接地，把冲击分散到多个轮子和连杆上。

#### 1.2 推荐尺寸（配 65mm 左右 TT 越野轮）

| 零件 | 建议尺寸 | 说明 |
| --- | --- | --- |
| 中央车身盒 | 约 100–160mm 长 | 放电池、ESP32、L298N、LM2596 |
| 每侧长摇臂 | 约 220–260mm | 前端固定前轮，后端连接小转向架 |
| 每侧小转向架 | 约 140–170mm | 两端固定中轮、后轮，中间接长摇臂 |
| 主铰链 A | M4/M5/M6 螺丝 + 垫片 | 必须能转动，不能粘死 |
| 二级铰链 B | M4/M5 螺丝 + 垫片 | 必须能转动，不能粘死 |

孔位示意：

```text
长摇臂：
前轮电机位        主铰链 A              二级铰链 B
   O──────────────O────────────────────O

小转向架：
中轮电机位        二级铰链 B            后轮电机位
   O──────────────O────────────────────O
```

#### 1.3 制作步骤

1. 先做中央车身盒：用 ABS 接线盒、塑料盒、木板盒或亚克力盒作为主控舱，两侧各加一块侧板，用来安装主铰链 A。
2. 做左右两根长摇臂：材料可用 10x10mm 铝方管、木条、PVC 扁条、亚克力条或金属尺。左右必须尽量等长。
3. 做左右两个小转向架：中间打孔接二级铰链 B，两端分别固定中轮和后轮电机。
4. 铰链处用“螺丝 + 垫片 + 螺母”，不要用热熔胶粘死。拧紧后稍微回松，让摇臂能自由摆动但不要明显晃动。
5. 每个 TT 电机最好先固定在小电机座或小木片上，再用扎带穿孔固定到摇臂末端，最后少量热熔胶防滑。不要只靠一大坨热熔胶承重。
6. 在摇臂可能撞到车身的位置贴海绵、EVA 或泡沫块作为限位缓冲。也可以用橡皮筋轻轻拉住摇臂，让它回到中间角度，但橡皮筋不要作为主要承重件。
7. 电机线必须留出弯折余量，避免摇臂上下摆动时把线拉断。

#### 1.4 第一版简化方案

如果制作难度太高，可以先做“简化 Rocker-Bogie”：

- 不做每个轮子的独立转向；
- 六个轮子方向固定；
- 用左右两侧差速 / 坦克转向完成转弯；
- 先用便宜的 `1:48 TT 电机` 验证结构和接线，成功后再统一换成 `1:90` 或 `1:120`。

注意：六个驱动电机必须尽量使用同一减速比，不要左右混用不同减速比，否则会明显跑偏。

### 步骤 2：连接动力与供电网络

- 串联电池：将两节18650电池放入电池盒（提供约7.4V电压）。
- 电源分配：
  - 将7.4V直接连接到两个 L298N 驱动模块的 12V 输入 引脚（提供充足动力）。
  - 将7.4V连接到 LM2596 降压模块的输入端，调节降压模块上的电位器，用万用表测出精确的 5.0V 输出。
  - 将降压后的 5V 供给 ESP32、ESP32-CAM 和所有的传感器。
- 接线电机：左侧3个电机的正负极并联，接入第一个 L298N；右侧3个电机并联，接入第二个 L298N。这样你可以像控制坦克一样，通过左右履带的速度差来转向（甚至原地打转）。
- 固定驱动与电源舱：借鉴 OpenRover 的中央模块化布置，把电池盒、LM2596、L298N 和主控板都尽量集中安装在中央机身支架内部或侧面，避免挂在悬挂端增加非簧载质量。

### 步骤 3：部署“大脑”与传感器

- 直行保障 (MPU6050)：将其固定在车体正中央。代码中需要写一个 PID 控制器，如果陀螺仪发现车头偏向左，就稍微降低右侧电机的速度，强制车身走直线。
- 防撞系统 (超声波)：在车头品字形安装3个HC-SR04。代码逻辑：当前方距离 < 20cm 时，停止 -> 读取左右超声波数据 -> 向距离大的一侧转向。
- 视觉云台 (ESP32-CAM)：将 SG90 舵机固定在车顶，把 ESP32-CAM 粘在舵机臂上。
- 机械臂结构（借鉴 OpenRover）：在车体前部或中央机身上表面安装一个轻量折叠式机械臂底座。机械臂建议采用 `4 轴折叠结构 + 小夹爪` 的形式，运输时可折叠贴近车身，工作时再展开。为了保持当前方案不变，本版只修改机械结构参考，不要求你立刻引入额外主控板或复杂逆运动学。

### 步骤 3.5：制作保温与温度保护系统（-20°~50°目标）

本项目的温度目标应分成两层理解：

- **模型演示层面**：用保温盒、温度传感器和程序保护逻辑，展示火星车具备“低温休眠、高温保护”的工程设计。
- **真实工程层面**：普通 TT 电机、18650 电池、ESP32 模块并不等于真的可以长期在 -20°C 到 50°C 环境中满负荷工作。因此本项目不建议使用没有温控的电阻加热片或把锂电池放进极端环境里测试。

#### 3.5.1 被动保温盒结构

把电池、ESP32、ESP32-CAM、传感器接口尽量放进中央主控舱内，做成“夹层保温盒”：

```text
外部环境
  │
  ▼
┌────────────────────┐
│ 外壳：ABS盒/塑料盒   │  防撞、防灰尘
│ ┌────────────────┐ │
│ │ 保温层：EVA/海绵 │ │  减少热量流失
│ │ ┌────────────┐ │ │
│ │ │ 空气层/泡沫 │ │ │  形成隔热缓冲
│ │ │ ESP32/电池  │ │ │  核心电子舱
│ │ └────────────┘ │ │
│ └────────────────┘ │
└────────────────────┘
```

可用材料：EVA 泡棉、薄海绵、泡沫板、瓦楞纸板、热缩管、绝缘胶带、少量铝箔胶带或急救毯反光膜。铝箔只能贴在外层或夹层，不能接触电路板焊点和电池极片，防止短路。

#### 3.5.2 冷环境策略

- 电池和主控板放在保温盒中心，不要贴在底盘外侧。
- L298N 会发热，不能完全包死；可让散热片靠近通风孔或外壳内壁。
- 低温时先进入 `COLD_START`：上电后原地等待 30–60 秒，让电子舱内部温度稳定，再低速行驶。
- 当温度过低时，火星车进入 `COLD_SLEEP`：关闭电机，只保留主控低功耗监测，等待光照或温度恢复。

#### 3.5.3 热环境策略

- 电子舱内部温度超过 45°C 时降低电机功率，减少 ESP32-CAM 连续图传。
- 温度超过 50°C 时进入 `THERMAL_PAUSE`：停车、停止拍摄、等待降温。
- 外壳顶部可使用浅色材料或反光膜；但太阳能板表面不能被覆盖。

#### 3.5.4 温度传感器选项

建议加一个可选温度传感器，便于在电脑端显示内部温度：

- 简单方案：`DS18B20` 数字温度探头，装在主控舱内部靠近电池的位置。
- 替代方案：`10k NTC` 温度模块，接 ESP32 的 ADC 输入脚。

推荐程序规则：

```text
inside_temp < -10°C  -> COLD_SLEEP，禁止电机运行
-10°C ~ 0°C          -> COLD_START，只允许低速短时运行
0°C ~ 45°C           -> NORMAL，正常运行
45°C ~ 50°C          -> HOT_LIMIT，降低速度和拍摄频率
inside_temp > 50°C   -> THERMAL_PAUSE，停车降温
```

#### 3.5.5 安全边界

- 不要用裸电阻丝、没有温控的加热片直接贴在 18650 电池上。
- 不要让铝箔、金属胶带、螺丝接触电池正负极或电路板焊点。
- 不要把 L298N、LM2596 完全包进厚海绵里运行，防止自身过热。
- 真正低温测试时，不建议把锂电池放进冰箱或冷冻环境反复测试；课堂模型可用冰袋放在盒子外侧进行短时间模拟，并全程人工看护。

### 步骤 4：实现 3D 和 360° 摄影“黑科技”

预算有限买不起3D镜头，我们用软件弥补：

- 360°全景逻辑：主控板发送指令，让舵机从 0° 转到 180°，每转 30° 让 ESP32-CAM 拍一张照并传给电脑。电脑端使用 Python 脚本（利用 OpenCV 库）自动将图片拼接成全景图。
- 3D照片逻辑：利用双目视差原理。让火星车在原地拍一张照 (左眼视角) -> 火星车绝对直线向前移动 6 厘米 -> 再拍第二张照 (右眼视角)。将两张图片传给电脑，可以通过软件合成为红蓝3D图片或立体图。

### 步骤 5：编写“3个月火星生存”休眠代码逻辑

由于不能真的跑3个月，我们可以用代码模拟时间流逝（例如现实中1天等于火星上1周）：

- 光控唤醒：将光敏电阻 (LDR) 连接到 ESP32 的唤醒引脚。
- 深度休眠 (Deep Sleep)：写一段逻辑，当 LDR 检测不到光（黑夜），ESP32 进入 Deep Sleep 模式（功耗仅几微安），同时关闭电机供电。
- 充电与唤醒：天亮时，太阳能板通过 2S BMS 为 2 节串联 18650 电池补能。LDR 电阻值变化，唤醒 ESP32。
- 最后10天的“冲刺模式”：
  - ESP32 内部使用 RTC (实时时钟) 内存记录自己醒来的次数。
  - 假设设计为唤醒 80 次后（代表进入最后生命周期），触发 Final_Mission_Mode()。
  - 在此模式下，火星车无视光照和电量警告，全速运行，高频调用 ESP32-CAM 拍摄所需的50张全景照片和100张3D照片素材，并通过超声波和陀螺仪数据在电脑端绘制出其走过的地图路线，直到电池彻底耗尽，光荣完成使命。

## 风险与待确认项

- `OpenRover` 公开资料中的机械平台是 `6-wheel drive + 4 steerable wheels`，而你当前指南其余部分仍保持 `TT motor + 双 L298N + 差速驱动`，因此本版只借鉴机械安装方式，不代表已经改成四轮转向平台。
- `OpenRover` 的机械臂是 `4-axis foldable robotic arm with gripper`，但你的当前电气与控制方案并未正式给机械臂分配独立供电和控制通道，因此本版中的机械臂默认是结构预留或第二阶段扩展。
- 如果后续真的加入机械臂，需重新评估预算、重心、供电、电流峰值和跌落可靠性。

安全警告: 处理18650锂电池时请注意正负极，切勿短路。调试电机时请先将火星车架空，防止意外跑飞。

## 本次修订说明

- 在 OpenRover 机械参考边界下，进一步展开了每侧长摇臂 + 小转向架的制作尺寸、孔位和铰链做法。
- 增加被动保温盒、温度监测和程序保护逻辑，作为 -20°~50°工作目标的模型化实现方案。
- 保持 `ESP32 + ESP32-CAM` 双脑和 `TT motor + L298N` 基线，不把整车改成 OpenRover 的完整电控平台。

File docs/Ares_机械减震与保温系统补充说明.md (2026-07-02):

# Ares 机械减震与保温系统补充说明

### 步骤 1：搭建“摇臂-转向架”底盘与机械减震系统

本项目的“机械减震”不采用汽车弹簧减震器，而采用火星车常见的 `Rocker-Bogie / 摇臂-转向架`。它的核心不是“弹簧变软”，而是让每侧 3 个轮子通过两个活动铰链上下摆动，使轮子遇到障碍时车身不会被直接顶起。

#### 1.1 一侧三轮的结构

每一侧由一根长摇臂和一根小转向架组成：

```text
一侧侧视图：

                 中央车身盒 / 主控舱
             ┌────────────────────┐
             │ ESP32 / 电池 / 驱动 │
             └─────────O──────────┘
                       │ 主铰链 A
                       │
前轮电机+轮子  ○────────┘────────O  二级铰链 B
                                  │
                           中轮 ○─┴─○ 后轮
                              小转向架 Bogie
```

拆开看就是：

```text
长摇臂 Rocker：
前轮电机位 ───── 主铰链 A ───── 二级铰链 B

小转向架 Bogie：
中轮电机位 ───── 二级铰链 B ───── 后轮电机位
```

- 前轮压到障碍物时，长摇臂绕主铰链 A 转动。
- 中轮或后轮压到障碍物时，小转向架绕二级铰链 B 转动。
- 这样可以让六个轮子尽量保持接地，把冲击分散到多个轮子和连杆上。

#### 1.2 推荐尺寸（配 65mm 左右 TT 越野轮）

| 零件 | 建议尺寸 | 说明 |
| --- | --- | --- |
| 中央车身盒 | 约 100–160mm 长 | 放电池、ESP32、L298N、LM2596 |
| 每侧长摇臂 | 约 220–260mm | 前端固定前轮，后端连接小转向架 |
| 每侧小转向架 | 约 140–170mm | 两端固定中轮、后轮，中间接长摇臂 |
| 主铰链 A | M4/M5/M6 螺丝 + 垫片 | 必须能转动，不能粘死 |
| 二级铰链 B | M4/M5 螺丝 + 垫片 | 必须能转动，不能粘死 |

孔位示意：

```text
长摇臂：
前轮电机位        主铰链 A              二级铰链 B
   O──────────────O────────────────────O

小转向架：
中轮电机位        二级铰链 B            后轮电机位
   O──────────────O────────────────────O
```

#### 1.3 制作步骤

1. 先做中央车身盒：用 ABS 接线盒、塑料盒、木板盒或亚克力盒作为主控舱，两侧各加一块侧板，用来安装主铰链 A。
2. 做左右两根长摇臂：材料可用 10x10mm 铝方管、木条、PVC 扁条、亚克力条或金属尺。左右必须尽量等长。
3. 做左右两个小转向架：中间打孔接二级铰链 B，两端分别固定中轮和后轮电机。
4. 铰链处用“螺丝 + 垫片 + 螺母”，不要用热熔胶粘死。拧紧后稍微回松，让摇臂能自由摆动但不要明显晃动。
5. 每个 TT 电机最好先固定在小电机座或小木片上，再用扎带穿孔固定到摇臂末端，最后少量热熔胶防滑。不要只靠一大坨热熔胶承重。
6. 在摇臂可能撞到车身的位置贴海绵、EVA 或泡沫块作为限位缓冲。也可以用橡皮筋轻轻拉住摇臂，让它回到中间角度，但橡皮筋不要作为主要承重件。
7. 电机线必须留出弯折余量，避免摇臂上下摆动时把线拉断。

#### 1.4 第一版简化方案

如果制作难度太高，可以先做“简化 Rocker-Bogie”：

- 不做每个轮子的独立转向；
- 六个轮子方向固定；
- 用左右两侧差速 / 坦克转向完成转弯；
- 先用便宜的 `1:48 TT 电机` 验证结构和接线，成功后再统一换成 `1:90` 或 `1:120`。

注意：六个驱动电机必须尽量使用同一减速比，不要左右混用不同减速比，否则会明显跑偏。

### 步骤 3.5：制作保温与温度保护系统（-20°~50°目标）

本项目的温度目标应分成两层理解：

- **模型演示层面**：用保温盒、温度传感器和程序保护逻辑，展示火星车具备“低温休眠、高温保护”的工程设计。
- **真实工程层面**：普通 TT 电机、18650 电池、ESP32 模块并不等于真的可以长期在 -20°C 到 50°C 环境中满负荷工作。因此本项目不建议使用没有温控的电阻加热片或把锂电池放进极端环境里测试。

#### 3.5.1 被动保温盒结构

把电池、ESP32、ESP32-CAM、传感器接口尽量放进中央主控舱内，做成“夹层保温盒”：

```text
外部环境
  │
  ▼
┌────────────────────┐
│ 外壳：ABS盒/塑料盒   │  防撞、防灰尘
│ ┌────────────────┐ │
│ │ 保温层：EVA/海绵 │ │  减少热量流失
│ │ ┌────────────┐ │ │
│ │ │ 空气层/泡沫 │ │ │  形成隔热缓冲
│ │ │ ESP32/电池  │ │ │  核心电子舱
│ │ └────────────┘ │ │
│ └────────────────┘ │
└────────────────────┘
```

可用材料：EVA 泡棉、薄海绵、泡沫板、瓦楞纸板、热缩管、绝缘胶带、少量铝箔胶带或急救毯反光膜。铝箔只能贴在外层或夹层，不能接触电路板焊点和电池极片，防止短路。

#### 3.5.2 冷环境策略

- 电池和主控板放在保温盒中心，不要贴在底盘外侧。
- L298N 会发热，不能完全包死；可让散热片靠近通风孔或外壳内壁。
- 低温时先进入 `COLD_START`：上电后原地等待 30–60 秒，让电子舱内部温度稳定，再低速行驶。
- 当温度过低时，火星车进入 `COLD_SLEEP`：关闭电机，只保留主控低功耗监测，等待光照或温度恢复。

#### 3.5.3 热环境策略

- 电子舱内部温度超过 45°C 时降低电机功率，减少 ESP32-CAM 连续图传。
- 温度超过 50°C 时进入 `THERMAL_PAUSE`：停车、停止拍摄、等待降温。
- 外壳顶部可使用浅色材料或反光膜；但太阳能板表面不能被覆盖。

#### 3.5.4 温度传感器选项

建议加一个可选温度传感器，便于在电脑端显示内部温度：

- 简单方案：`DS18B20` 数字温度探头，装在主控舱内部靠近电池的位置。
- 替代方案：`10k NTC` 温度模块，接 ESP32 的 ADC 输入脚。

推荐程序规则：

```text
inside_temp < -10°C  -> COLD_SLEEP，禁止电机运行
-10°C ~ 0°C          -> COLD_START，只允许低速短时运行
0°C ~ 45°C           -> NORMAL，正常运行
45°C ~ 50°C          -> HOT_LIMIT，降低速度和拍摄频率
inside_temp > 50°C   -> THERMAL_PAUSE，停车降温
```

#### 3.5.5 安全边界

- 不要用裸电阻丝、没有温控的加热片直接贴在 18650 电池上。
- 不要让铝箔、金属胶带、螺丝接触电池正负极或电路板焊点。
- 不要把 L298N、LM2596 完全包进厚海绵里运行，防止自身过热。
- 真正低温测试时，不建议把锂电池放进冰箱或冷冻环境反复测试；课堂模型可用冰袋放在盒子外侧进行短时间模拟，并全程人工看护。

## 建议实际制作顺序

1. 先用纸板或木条做一侧 Rocker-Bogie 小模型，只验证两个铰链能否摆动。
2. 再把这一侧复制成左右两侧，固定到中央车身盒。
3. 先不装全部电子元件，只装 6 个轮子和电机，推动车子看六轮是否都能接地。
4. 接 L298N 和 ESP32，先让车架空测试六个轮子的方向。
5. 最后再装保温盒、温度传感器、摄像头和太阳能板。

## 最小可行版本

- 六轮方向固定，不做独立转向。
- V1 使用 1:48 TT 电机验证结构。
- Rocker-Bogie 只做两个能活动的铰链：每侧主铰链 A + 二级铰链 B。
- 保温系统先做被动保温盒，不上主动加热。
- 温度传感器可选；如果没有传感器，可以先用“保温结构说明 + 程序伪代码”满足作业展示。

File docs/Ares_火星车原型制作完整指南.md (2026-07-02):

# Operation MROS

IMPORTANT

## 🛒

为了实现复杂的功能，我们将采用“双脑”架构：一个ESP32负责控制和传感器，另一个ESP32-CAM专门负责图像处理和传输。

### 1. 核心大脑与视觉

- 1x ESP32 开发板 (NodeMCU): $6 (主控芯片，负责电机、超声波、陀螺仪、休眠逻辑)
- 1x ESP32-CAM 模块 (带OV2640摄像头): $7 (负责拍照、Wi-Fi图传)
- 1x SG90 微型舵机: $2 (用于搭载ESP32-CAM，实现360°旋转扫描)

### 2. 动力与底盘系统

- 6x TT 直流减速电机 + 配套越野轮胎: $15-$25 (V1 可先用便宜 1:48 验证结构；V2 推荐统一升级到 1:90，重车或强调爬坡可考虑 1:120)
- 2x L298N 电机驱动模块: $6 (一个控制左侧3个轮子，一个控制右侧3个轮子)
- 底盘与悬挂材料: $5-$15 (推荐用 PVC 管、木条、亚克力条或铝方管制作 Rocker-Bogie 摇臂-转向架；铰链用螺丝、垫片和防松螺母，不要粘死)

### 3. 导航与避障传感器

- 3x HC-SR04 超声波传感器: $5 (分别安装在正前方、左前和右前，用于防撞和自动驾驶寻路)
- 1x MPU6050 陀螺仪/加速度计模块: $3 (极其重要：用于修正电机转速差，确保能在5米内走绝对直线)
- 1x 光敏电阻模块 (LDR): $1 (用于检测光照强度，决定是否唤醒火星车)

### 4. 能源与供电系统

- 1x 5V 小型太阳能电池板 (约130x150mm): $5 (安装在车顶)
- 1x 2S BMS 锂电池保护板: $2-$4 (用于 2 节 18650 串联电池的过充、过放和短路保护；TP4056 只适合单节锂电池，不作为本项目主方案)
- 2x 18650 锂电池 + 1x 双节电池盒: $10 (主电源)
- 1x LM2596 降压模块 (DC-DC): $3 (将电池的7.4V降压至5V，供ESP32和舵机使用)

### 5. 杂项与结构件

- 被动式岩石收集器: $0 (DIY：在车尾底部倾斜安装一个切开的硬塑料瓶或金属小铲，行驶时自然兜住小石块)
- 保温与热控材料: $3-$8 (EVA 泡棉、薄海绵、泡沫板、绝缘胶带、可选 DS18B20 温度传感器；用于实现 -20°~50°目标的保温与温度保护演示)
- 面包板、杜邦线 (公对公/公对母/母对母)、热熔胶枪、M3螺丝螺母、扎带、独立电源开关。

## 🛠️

### 步骤 1：搭建“摇臂-转向架”底盘与机械减震系统

本项目的“机械减震”不采用汽车弹簧减震器，而采用火星车常见的 `Rocker-Bogie / 摇臂-转向架`。它的核心不是“弹簧变软”，而是让每侧 3 个轮子通过两个活动铰链上下摆动，使轮子遇到障碍时车身不会被直接顶起。

#### 1.1 一侧三轮的结构

每一侧由一根长摇臂和一根小转向架组成：

```text
一侧侧视图：

                 中央车身盒 / 主控舱
             ┌────────────────────┐
             │ ESP32 / 电池 / 驱动 │
             └─────────O──────────┘
                       │ 主铰链 A
                       │
前轮电机+轮子  ○────────┘────────O  二级铰链 B
                                  │
                           中轮 ○─┴─○ 后轮
                              小转向架 Bogie
```

拆开看就是：

```text
长摇臂 Rocker：
前轮电机位 ───── 主铰链 A ───── 二级铰链 B

小转向架 Bogie：
中轮电机位 ───── 二级铰链 B ───── 后轮电机位
```

- 前轮压到障碍物时，长摇臂绕主铰链 A 转动。
- 中轮或后轮压到障碍物时，小转向架绕二级铰链 B 转动。
- 这样可以让六个轮子尽量保持接地，把冲击分散到多个轮子和连杆上。

#### 1.2 推荐尺寸（配 65mm 左右 TT 越野轮）

| 零件 | 建议尺寸 | 说明 |
| --- | --- | --- |
| 中央车身盒 | 约 100–160mm 长 | 放电池、ESP32、L298N、LM2596 |
| 每侧长摇臂 | 约 220–260mm | 前端固定前轮，后端连接小转向架 |
| 每侧小转向架 | 约 140–170mm | 两端固定中轮、后轮，中间接长摇臂 |
| 主铰链 A | M4/M5/M6 螺丝 + 垫片 | 必须能转动，不能粘死 |
| 二级铰链 B | M4/M5 螺丝 + 垫片 | 必须能转动，不能粘死 |

孔位示意：

```text
长摇臂：
前轮电机位        主铰链 A              二级铰链 B
   O──────────────O────────────────────O

小转向架：
中轮电机位        二级铰链 B            后轮电机位
   O──────────────O────────────────────O
```

#### 1.3 制作步骤

1. 先做中央车身盒：用 ABS 接线盒、塑料盒、木板盒或亚克力盒作为主控舱，两侧各加一块侧板，用来安装主铰链 A。
2. 做左右两根长摇臂：材料可用 10x10mm 铝方管、木条、PVC 扁条、亚克力条或金属尺。左右必须尽量等长。
3. 做左右两个小转向架：中间打孔接二级铰链 B，两端分别固定中轮和后轮电机。
4. 铰链处用“螺丝 + 垫片 + 螺母”，不要用热熔胶粘死。拧紧后稍微回松，让摇臂能自由摆动但不要明显晃动。
5. 每个 TT 电机最好先固定在小电机座或小木片上，再用扎带穿孔固定到摇臂末端，最后少量热熔胶防滑。不要只靠一大坨热熔胶承重。
6. 在摇臂可能撞到车身的位置贴海绵、EVA 或泡沫块作为限位缓冲。也可以用橡皮筋轻轻拉住摇臂，让它回到中间角度，但橡皮筋不要作为主要承重件。
7. 电机线必须留出弯折余量，避免摇臂上下摆动时把线拉断。

#### 1.4 第一版简化方案

如果制作难度太高，可以先做“简化 Rocker-Bogie”：

- 不做每个轮子的独立转向；
- 六个轮子方向固定；
- 用左右两侧差速 / 坦克转向完成转弯；
- 先用便宜的 `1:48 TT 电机` 验证结构和接线，成功后再统一换成 `1:90` 或 `1:120`。

注意：六个驱动电机必须尽量使用同一减速比，不要左右混用不同减速比，否则会明显跑偏。

### 步骤 2：连接动力与供电网络

- 串联电池：将两节18650电池放入电池盒（提供约7.4V电压）。
- 电源分配：
  - 将7.4V直接连接到两个 L298N 驱动模块的 12V 输入 引脚（提供充足动力）。
  - 将7.4V连接到 LM2596 降压模块的输入端，调节降压模块上的电位器，用万用表测出精确的 5.0V 输出。
  - 将降压后的 5V 供给 ESP32、ESP32-CAM 和所有的传感器。
- 接线电机：左侧3个电机的正负极并联，接入第一个 L298N；右侧3个电机并联，接入第二个 L298N。这样你可以像控制坦克一样，通过左右履带的速度差来转向（甚至原地打转）。

### 步骤 3：部署“大脑”与传感器

- 直行保障 (MPU6050)：将其固定在车体正中央。代码中需要写一个 PID 控制器，如果陀螺仪发现车头偏向左，就稍微降低右侧电机的速度，强制车身走直线。
- 防撞系统 (超声波)：在车头品字形安装3个HC-SR04。代码逻辑：当前方距离 < 20cm 时，停止 -> 读取左右超声波数据 -> 向距离大的一侧转向。
- 视觉云台 (ESP32-CAM)：将 SG90 舵机固定在车顶，把 ESP32-CAM 粘在舵机臂上。

### 步骤 3.5：制作保温与温度保护系统（-20°~50°目标）

本项目的温度目标应分成两层理解：

- **模型演示层面**：用保温盒、温度传感器和程序保护逻辑，展示火星车具备“低温休眠、高温保护”的工程设计。
- **真实工程层面**：普通 TT 电机、18650 电池、ESP32 模块并不等于真的可以长期在 -20°C 到 50°C 环境中满负荷工作。因此本项目不建议使用没有温控的电阻加热片或把锂电池放进极端环境里测试。

#### 3.5.1 被动保温盒结构

把电池、ESP32、ESP32-CAM、传感器接口尽量放进中央主控舱内，做成“夹层保温盒”：

```text
外部环境
  │
  ▼
┌────────────────────┐
│ 外壳：ABS盒/塑料盒   │  防撞、防灰尘
│ ┌────────────────┐ │
│ │ 保温层：EVA/海绵 │ │  减少热量流失
│ │ ┌────────────┐ │ │
│ │ │ 空气层/泡沫 │ │ │  形成隔热缓冲
│ │ │ ESP32/电池  │ │ │  核心电子舱
│ │ └────────────┘ │ │
│ └────────────────┘ │
└────────────────────┘
```

可用材料：EVA 泡棉、薄海绵、泡沫板、瓦楞纸板、热缩管、绝缘胶带、少量铝箔胶带或急救毯反光膜。铝箔只能贴在外层或夹层，不能接触电路板焊点和电池极片，防止短路。

#### 3.5.2 冷环境策略

- 电池和主控板放在保温盒中心，不要贴在底盘外侧。
- L298N 会发热，不能完全包死；可让散热片靠近通风孔或外壳内壁。
- 低温时先进入 `COLD_START`：上电后原地等待 30–60 秒，让电子舱内部温度稳定，再低速行驶。
- 当温度过低时，火星车进入 `COLD_SLEEP`：关闭电机，只保留主控低功耗监测，等待光照或温度恢复。

#### 3.5.3 热环境策略

- 电子舱内部温度超过 45°C 时降低电机功率，减少 ESP32-CAM 连续图传。
- 温度超过 50°C 时进入 `THERMAL_PAUSE`：停车、停止拍摄、等待降温。
- 外壳顶部可使用浅色材料或反光膜；但太阳能板表面不能被覆盖。

#### 3.5.4 温度传感器选项

建议加一个可选温度传感器，便于在电脑端显示内部温度：

- 简单方案：`DS18B20` 数字温度探头，装在主控舱内部靠近电池的位置。
- 替代方案：`10k NTC` 温度模块，接 ESP32 的 ADC 输入脚。

推荐程序规则：

```text
inside_temp < -10°C  -> COLD_SLEEP，禁止电机运行
-10°C ~ 0°C          -> COLD_START，只允许低速短时运行
0°C ~ 45°C           -> NORMAL，正常运行
45°C ~ 50°C          -> HOT_LIMIT，降低速度和拍摄频率
inside_temp > 50°C   -> THERMAL_PAUSE，停车降温
```

#### 3.5.5 安全边界

- 不要用裸电阻丝、没有温控的加热片直接贴在 18650 电池上。
- 不要让铝箔、金属胶带、螺丝接触电池正负极或电路板焊点。
- 不要把 L298N、LM2596 完全包进厚海绵里运行，防止自身过热。
- 真正低温测试时，不建议把锂电池放进冰箱或冷冻环境反复测试；课堂模型可用冰袋放在盒子外侧进行短时间模拟，并全程人工看护。

### 步骤 4：实现 3D 和 360° 摄影“黑科技”

预算有限买不起3D镜头，我们用软件弥补：

- 360°全景逻辑：主控板发送指令，让舵机从 0° 转到 180°，每转 30° 让 ESP32-CAM 拍一张照并传给电脑。电脑端使用 Python 脚本（利用 OpenCV 库）自动将图片拼接成全景图。
- 3D照片逻辑：利用双目视差原理。让火星车在原地拍一张照 (左眼视角) -> 火星车绝对直线向前移动 6 厘米 -> 再拍第二张照 (右眼视角)。将两张图片传给电脑，可以通过软件合成为红蓝3D图片或立体图。

### 步骤 5：编写“3个月火星生存”休眠代码逻辑

由于不能真的跑3个月，我们可以用代码模拟时间流逝（例如现实中1天等于火星上1周）：

- 光控唤醒：将光敏电阻 (LDR) 连接到 ESP32 的唤醒引脚。
- 深度休眠 (Deep Sleep)：写一段逻辑，当 LDR 检测不到光（黑夜），ESP32 进入 Deep Sleep 模式（功耗仅几微安），同时关闭电机供电。
- 充电与唤醒：天亮时，太阳能板通过 2S BMS 为 2 节串联 18650 电池补能。LDR 电阻值变化，唤醒 ESP32。
- 最后10天的“冲刺模式”：
  - ESP32 内部使用 RTC (实时时钟) 内存记录自己醒来的次数。
  - 假设设计为唤醒 80 次后（代表进入最后生命周期），触发 Final_Mission_Mode()。
  - 在此模式下，火星车无视光照和电量警告，全速运行，高频调用 ESP32-CAM 拍摄所需的50张全景照片和100张3D照片素材，并通过超声波和陀螺仪数据在电脑端绘制出其走过的地图路线，直到电池彻底耗尽，光荣完成使命。

安全警告: 处理18650锂电池时请注意正负极，切勿短路。调试电机时请先将火星车架空，防止意外跑飞。

## 本次修订说明

- 明确机械减震采用 `Rocker-Bogie / 摇臂-转向架`，并补充尺寸、孔位、铰链、限位和电机固定方式。
- 增加保温与温度保护系统，采用被动保温盒 + 可选温度传感器 + 程序保护状态机。
- 将 2 节 18650 串联场景下的主充电/保护方案统一为 `2S BMS`，避免误用只适合单节锂电池的 TP4056。

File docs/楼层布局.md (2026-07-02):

> **最小包络体积推导：** > 由于二楼的洞洞板是 80×60mm，两块 L298N 并排至少需要 86×43mm。因此，碳纤维主甲板的尺寸建议设定为 **90mm (长) × 70mm (宽)**。

## 负一楼 (B1)：重力压舱层

- **入驻设备：** 双节 18650 电池盒
    
- **布局规范：**
    
    - 放置在底盘正中央，确保整车重心最低，防止 25° 陡坡翻车。
        
    - **固定方式：** 碳纤维底板上切出两道细槽，用尼龙魔术贴绑带死死勒住。不要用螺丝硬锁电池盒，容易震裂塑料。
        
- **楼层高度：** 使用 25mm 尼龙铜柱支撑上一层（预留 5mm 缝隙穿过魔术贴）。

## 一楼 (F1)：动力与配电层

- **入驻设备：** 两块 L298N 驱动板 + 一块 LM2596 降压模块
    
- **布局规范：**
    
    - **L298N 靠边站：** 把两块 L298N 分别背靠背贴近主舱的**左边缘**和**右边缘**。因为它们要直接连接 6 个电机的粗动力线，靠边缘可以大幅缩短走线，且避免粗线横穿核心区。
        
    - **LM2596 夹缝生存：** 放置在两块 L298N 中间的空隙处。
        
- **楼层高度：** L298N 的散热片高达 27mm。必须使用 **35mm 尼龙铜柱** 支撑上一层，确保散热片距离二楼底面有至少 8mm 的安全绝缘距离。

## 二楼 (F2)：神经中枢层

- **入驻设备：** 80×60mm 洞洞板 (集成 ESP32 MAIN 与 MPU6050)
    
- **布局规范：**
    
    - 将 MPU6050 直接**焊接并死死用排针固定在 80×60 洞洞板上**（紧靠 ESP32）。这完美满足了“线长 < 10cm”且“绝对刚性、不晃动”的物理限制。
        
    - 洞洞板四周打 4 个 M3 圆孔，锁死在 35mm 的尼龙铜柱上。

## 天台 (Roof)：视野与交互层

- **入驻设备：** ESP32-CAM 监控塔 + 钮子总开关
    
- **布局规范：**
    
    - **取消太阳能板：** 释放全部车顶空间。
        
    - **视觉桅杆：** 在天台正中央竖立一段短铝管或 3D 打印支架，安装 SG90 舵机和 ESP32-CAM，实现 360° 无遮挡扫描。
        
    - **⚠️ 钮子开关的防滚装配：** 开关高达 65mm！**绝对不能笔直朝上安装**，跌落必断。
        
        - **解法：** 将开关**横向（水平）安装**在车身尾部的侧板上，并在开关两侧加装碳纤维“U型防撞护翼”，护翼必须比开关拨杆长出至少 5mm。

## 外围防线 (Perimeter)：探测与行走

- **车头：** 用一块碳纤维横板或 3D 打印件，将 3 个超声波雷达（45×20×18mm）固定在车头，避开前轮的上下摆动空间。
    
- **两侧：** 纯净的 Rocker-Bogie 悬挂。6 个 70×20×20mm 的电机仅固定在摇臂末端，与主舱彻底解耦。

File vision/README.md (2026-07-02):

# vision/ — 电脑端工具集

负责收图、遥测记录与三大任务的后处理（全景 / 伪 3D / 地图）。全部是命令行脚本，Python ≥ 3.9。

```bash
pip install -r requirements.txt
```

| 脚本 | 作用 | 何时用 |
| --- | --- | --- |
| `mock_rover.py` | 假火星车（模拟 Commander 的 WebSocket 接口） | 无硬件时联调 dashboard、生成演示数据 |
| `receive_server.py` | 收图 HTTP 服务，存照片到 `incoming/` | 火星车拍摄时**必须一直开着** |
| `telemetry_logger.py` | 记录遥测为 JSONL 到 `logs/` | 想画地图的行驶全程开着 |
| `stitch_panorama.py` | 全景拼接（OpenCV，失败自动保底横排） | 全景任务拍完后 |
| `make_anaglyph.py` | 左右眼照片 → 红蓝 3D 图 | 伪 3D 任务拍完后 |
| `plot_map.py` | 遥测航迹推算 → 轨迹+障碍点地图 PNG | 录完遥测日志后 |

## 典型流程

### A. 无硬件试跑（今天就能玩）

```bash
python mock_rover.py                 # 终端 1：假火星车
python telemetry_logger.py --host 127.0.0.1   # 终端 2：录遥测（可选）
# 浏览器打开 dashboard/index.html，地址填 127.0.0.1，切 AUTO 让它自己跑一会儿
python plot_map.py logs/telemetry_*.jsonl -o map.png --speed 30   # 画出模拟地图
```

### B. 实车任务日

```bash
python receive_server.py             # 终端 1：收图（车拍的照片都会进 incoming/）
python telemetry_logger.py --host <车IP>      # 终端 2：录遥测
# dashboard 里点"拍 360° 全景" / "拍伪 3D"，或让 AUTO 巡航建图
python stitch_panorama.py incoming/ -o panorama.jpg
python make_anaglyph.py --auto incoming/
python plot_map.py logs/telemetry_*.jsonl -o map.png --speed <T2实测速度>
```

## 说明

- `--speed` 是满油门实测速度（cm/s），来自 `docs/装配与测试指南.md` 的 T2 标定，
  和固件 `config.h` 的 `CM_PER_SEC_CRUISE` 保持一致，地图比例才准。
- 地图是演示级航迹推算（无编码器），误差随里程累积，适合几米范围的房间演示。
- 全景拼接要求相邻照片有约 30% 重叠：舵机步进 30° 配相机横向视场约 60°，正好满足。

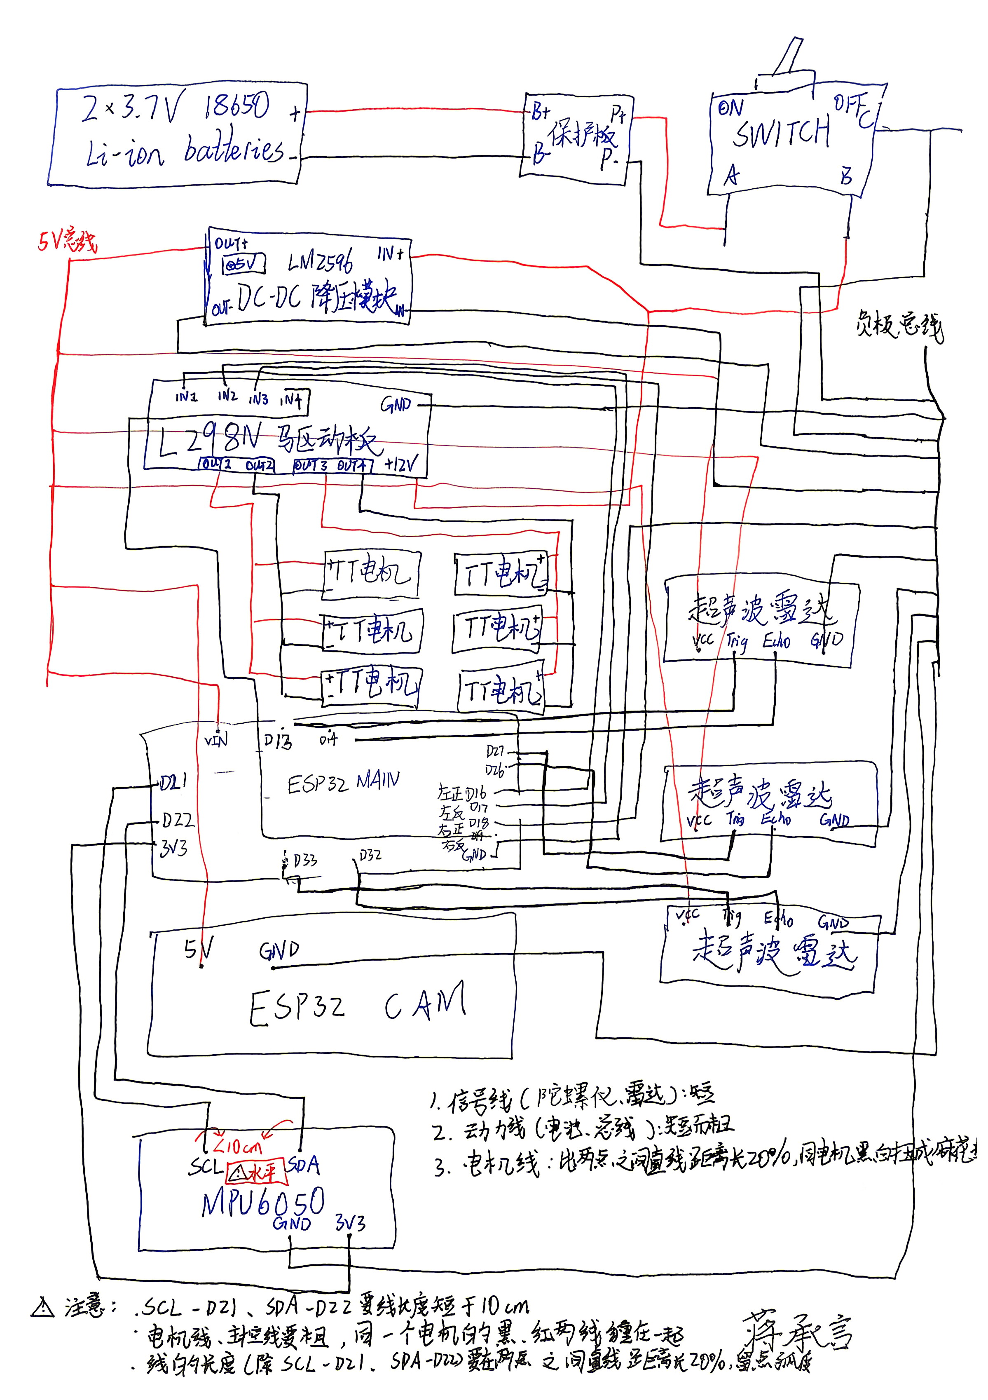
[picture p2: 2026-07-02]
hardware/drawings/线路图.jpg

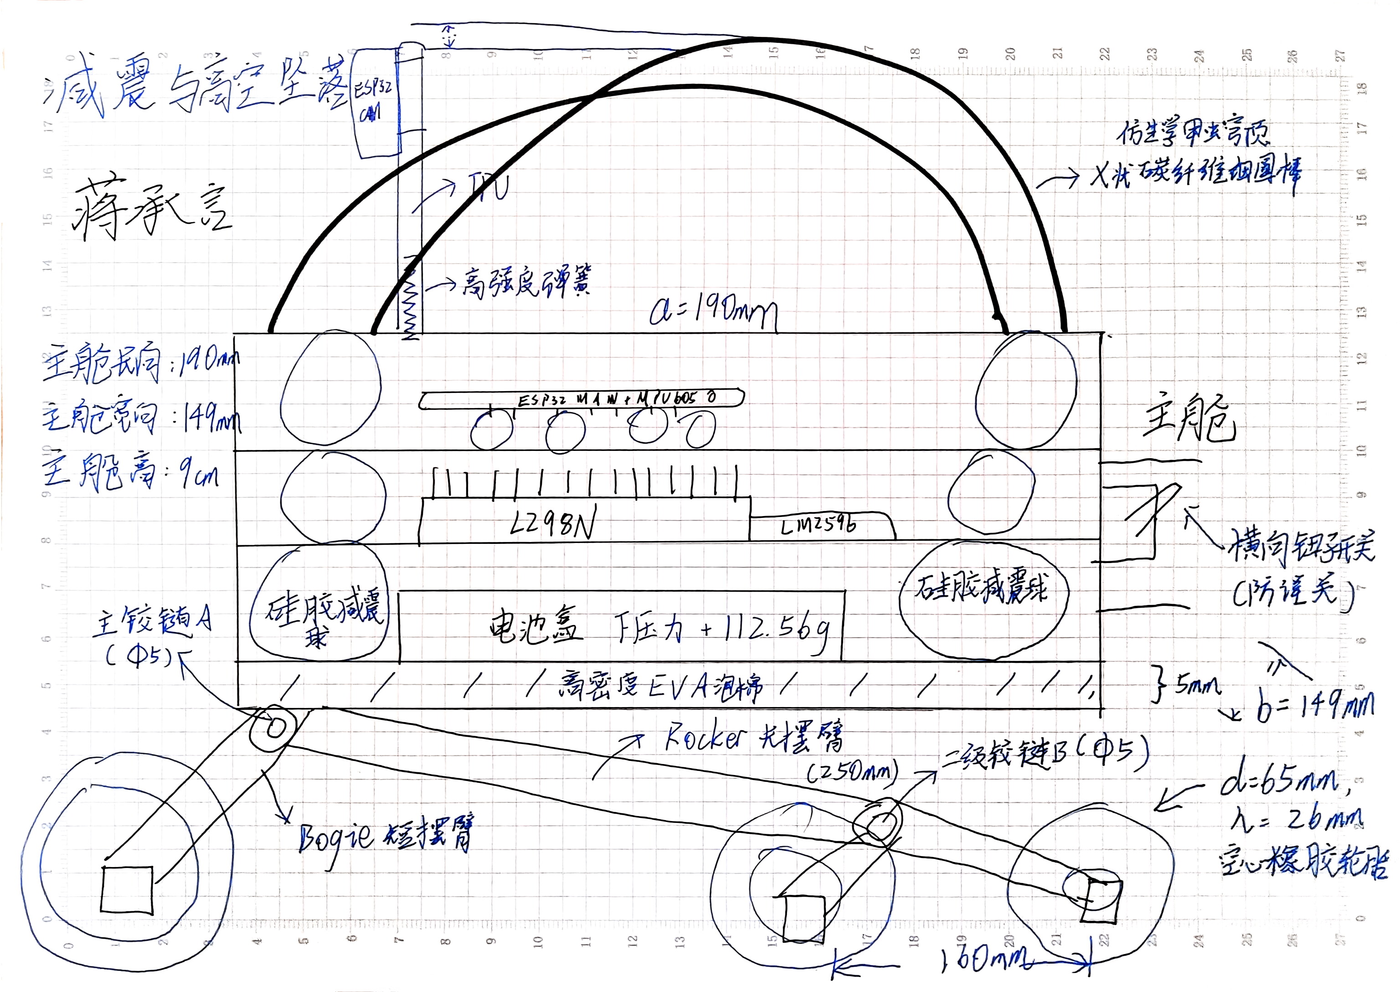
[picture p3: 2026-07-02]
hardware/drawings/总体设计.jpg

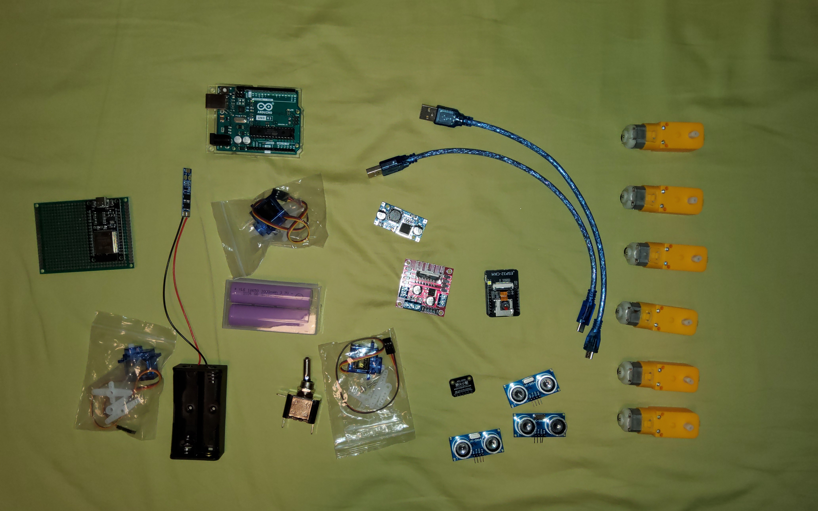
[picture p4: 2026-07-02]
hardware/drawings/部件.jpg

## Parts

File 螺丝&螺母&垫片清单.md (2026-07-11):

## 1. M3 基础固定系统 (主舱、电路、电机)

|零件类型及尺寸 (标准)|核心装配位置|建议数量|
|---|---|---|
|**M3 × 8mm** (半圆头或杯头螺丝)|固定电路板、主舱盖板、碳纤维层板|30 - 40 颗|
|**M3 × 30mm** (杯头螺丝)|穿透并锁死 6 个 TT 减速电机|12 - 15 颗|
|**M3** (普通六角螺母)|用于 M3 螺丝尾端锁死|40 - 50 颗|
|**M3 × 8 × 1** (尼龙绝缘平垫圈)|垫在电路板与碳纤维底盘之间 (绝缘防短路)|20 - 30 片|
|**M3 × 25mm** (双通尼龙支撑柱)|支撑主舱：负一楼 (电池层) 到 一楼 (驱动层)|4 根|
|**M3 × 35mm** (双通尼龙支撑柱)|支撑主舱：一楼 (驱动层) 到 二楼 (主控层)|4 根|

## 2. M4 悬挂敏捷关节 (长摇臂 ↔ 小转向架)

|零件类型及尺寸 (标准)|核心装配位置|建议数量|
|---|---|---|
|**M4 × 20mm** (杯头螺丝)|长摇臂 (Rocker) 与 小转向架 (Bogie) 连接主轴|4 - 6 颗|
|**M4** (尼龙防松螺母)|M4 关节尾端锁紧 (注意：保持顺滑，切勿拧死)|4 - 6 颗|
|**M4 × 9 × 0.8** (铁氟龙 PTFE 平垫)|夹在两块碳纤维悬挂板之间 (提供自润滑滑动面)|4 - 6 片|

## 3. M5 承重主铰链 (底盘主舱 ↔ 长摇臂)

|零件类型及尺寸 (标准)|核心装配位置|建议数量|
|---|---|---|
|**M5 × 30mm** (杯头螺丝 - 建议12.9级)|贯穿底盘侧板与长摇臂，承受全车落地的核心承重轴|4 颗|
|**M5** (尼龙防松螺母)|M5 主轴尾端锁紧 (注意：保持顺滑，切勿拧死)|4 颗|
|**M5 × 10 × 0.8** (铁氟龙 PTFE 平垫)|夹在底盘侧板与长摇臂之间 (防碳纤维暴力摩擦)|4 - 6 片|
|**M5 × 15** (加大金属平垫圈 - 选配)|垫在螺丝头最外侧和螺母最内侧 (分散极限冲击压强)|4 - 8 片|

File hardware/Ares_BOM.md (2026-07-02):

# PROJECT ARES V2.2 - 核心物料采购清单 (BOM)

设计预算 Target: $100.00 USD

## 1. 大脑与控制中枢 (指挥与导航)

- [ ] 1x ESP32 NodeMCU 开发板 (ESP-WROOM-32)  
  主指挥官。必须带 Wi-Fi 和蓝牙，引脚尽量多（通常是 38 针版本）。
- [ ] 1x ESP32-CAM 模块 (带 OV2640 摄像头排线)  
  3D 扫描仪与导航员。用于拍摄 360° 全景和传回电脑端处理。
- [ ] （可选）ESP32-CAM 下载器底板 (约 10 元)  
  强烈建议购买！ESP32-CAM 本身没有 USB 接口，带底板方便你用 USB 线烧录代码。

## 2. 能源与太阳能系统 (电力核心)

- [ ] 2x 18650 动力锂电池  
  建议购买大厂的正品电池（如 2500mAh 甚至 3000mAh），确保续航。
- [ ] 1x 18650 双节串联电池盒 (带引线)  
  注意：必须是串联（输出 7.4V），不能买并联（3.7V）的！
- [ ] 1x 2串 (2S) 锂电池 BMS 保护板  
  核心安全件。7.4V (8.4V满电) 充电必备，防止太阳能板过充导致电池起火。
- [ ] 1x LM2596 DC-DC 降压模块  
  必须带稳压调节旋钮。将 7.4V 电池电压稳稳降到 5.0V，保护主板不被烧毁。
- [ ] 3x 5V 微型太阳能滴胶板  
  尺寸推荐约 130mm x 150mm（几瓦功率即可）。一块固定在顶端，两块作为折叠翼。
- [ ] 1x 船型开关 / 拨动开关 (大电流)  
  安装在电池和降压模块之间，作为整车的总电源开关。

## 3. 动力与底盘行走系统 (六轮驱动)

- [ ] 6x TT 直流减速电机 (V1: 1:48；V2: 1:90；重车/爬坡版可选 1:120，双轴或单轴)  
  建议先用便宜 1:48 验证车架、接线和程序，成功后再统一换成 1:90；不要左右混用不同减速比。
- [ ] 6x 越野 TT 轮胎 (外径约 65mm)  
  表面有较深防滑胎纹的橡胶轮，专为沙地/火星模拟地形设计。
- [ ] 2x L298N 双路电机驱动模块  
  带巨大铝制散热片的那种经典红板。左侧三个电机并联接一块，右侧接另一块。

## 4. 传感器与执行机构 (有效载荷)

- [ ] 1x MPU6050 六轴陀螺仪/加速度计模块  
  姿态传感器。火星车能走“绝对直线”全靠它。
- [ ] 3x HC-SR04 超声波测距传感器  
  前置防撞“雷达”阵列。平价实现激光雷达的避障效果。
- [ ] 3x SG90 微型舵机 (180度版)  
  经典的蓝色小舵机。2个用于展开太阳能板，1个用于带动摄像头云台左右扫射。
- [ ] （可选）1x DS18B20 数字温度传感器 + 4.7kΩ 电阻  
  放在主控舱内部靠近电池的位置，用于显示内部温度，并触发低温休眠 / 高温保护。

## 5. 机械结构与骨架五金 (航天级底盘)

- [ ] 1x 20x20mm 铝合金方管 (壁厚 1-1.5mm，长 1 米)  
  中央脊椎主梁。非常轻但极其坚固。
- [ ] 1x 10x10mm 铝合金方管 (壁厚 1mm，长 1 米)  
  用于切割制作两侧的摇臂-转向架 (Rocker-Bogie) 悬挂臂。
- [ ] 结构挂载舱 (外壳) (约 15 元)  
  如果没有 3D 打印机，买几个 ABS 塑料防水接线盒（Project Box），尺寸约 100x60x40mm，钻孔后挂在铝管上。
- [ ] 螺丝螺母五金套装  
  `M4/M5/M6` 螺栓 + 垫片 + 尼龙防松螺母：用于 Rocker-Bogie 主铰链和二级铰链，必须顺滑且不松动。  
  `M3` 螺丝 + 尼龙/铜柱隔离柱：用于固定所有电路板（防短路）。
- [ ] 橡皮筋 / 小弹力绳 / 海绵块 / EVA 泡棉  
  用于摇臂限位、软缓冲和中央主控舱抗震。橡皮筋只负责回位和限位，不作为主要承重件。

## 6. 保温与热控材料

- [ ] EVA 泡棉 / 薄海绵 / 泡沫板 / 瓦楞纸板  
  用于制作中央电子舱的夹层保温盒，保护 ESP32、ESP32-CAM、18650 电池和传感器接口。
- [ ] 绝缘胶带 / 热缩管 / 扎带  
  用于防止铝箔、线头、焊点造成短路。
- [ ] （可选）铝箔胶带或急救毯反光膜  
  只能贴在外壳外侧或绝缘夹层中，不能接触电池极片或电路板焊点。

## 7. 线材与工具 (基础耗材)

- [ ] 杜邦线套装 (公对公、公对母、母对母各一排)
- [ ] 22 AWG 硅胶软线 (红黑两色，用于走大电流的电源和电机线)
- [ ] 热缩管 / 电工胶布 / 小扎带 (整理走线，防止航天器变成“盘丝洞”)
- [ ] 电烙铁及焊锡 (必须焊接马达引脚和总线)
- [ ] 手电钻 & 阶梯钻头/麻花钻头 (用于在铝合金方管上打孔)
- [ ] 钢锯 (截断铝管使用)

> 提示：在淘宝搜索元件时，直接复制条目中的核心关键词即可找到精准匹配的零件。

## 本次修订说明

- 电机采购改为“V1 1:48 验证，V2 1:90 / 1:120 升级”的路线。
- 增加 DS18B20 温度传感器、保温材料、摇臂限位和缓冲材料。
- 明确 Rocker-Bogie 铰链需要螺丝、垫片和防松螺母，不能用热熔胶粘死。

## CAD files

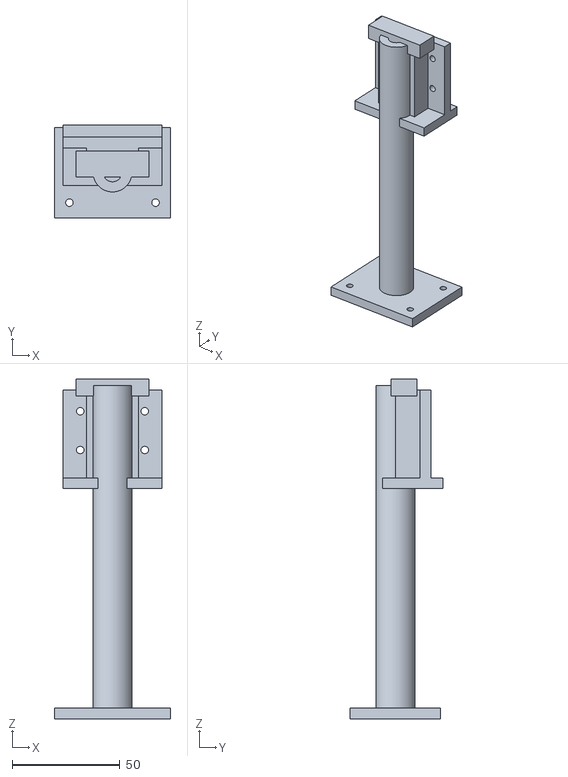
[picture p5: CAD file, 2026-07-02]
hardware/cad/柱子.stl
54.0 x 43.0 x 158.0

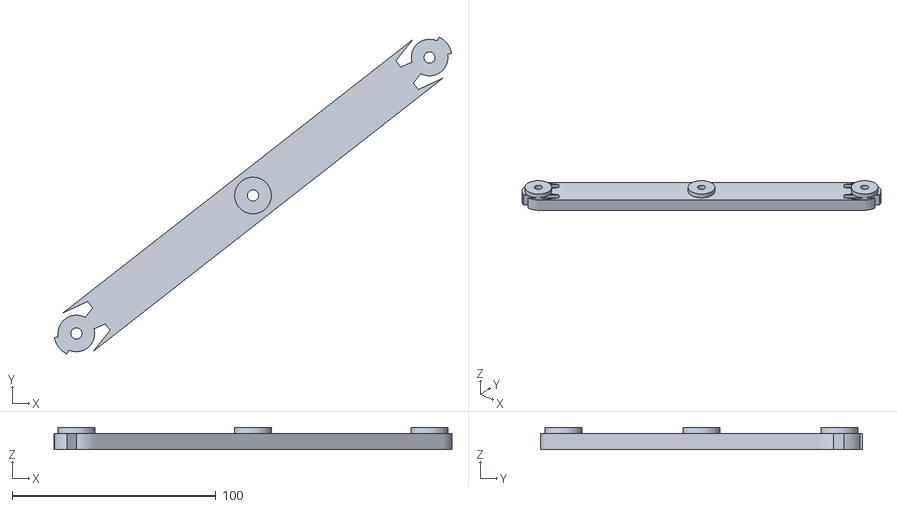
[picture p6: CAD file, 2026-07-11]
PLATE_05_RIGHT_ROCKER_DIAGONAL_FITS_256_ARES_FIXED_V9.stl
195.4 x 158.2 x 11.0

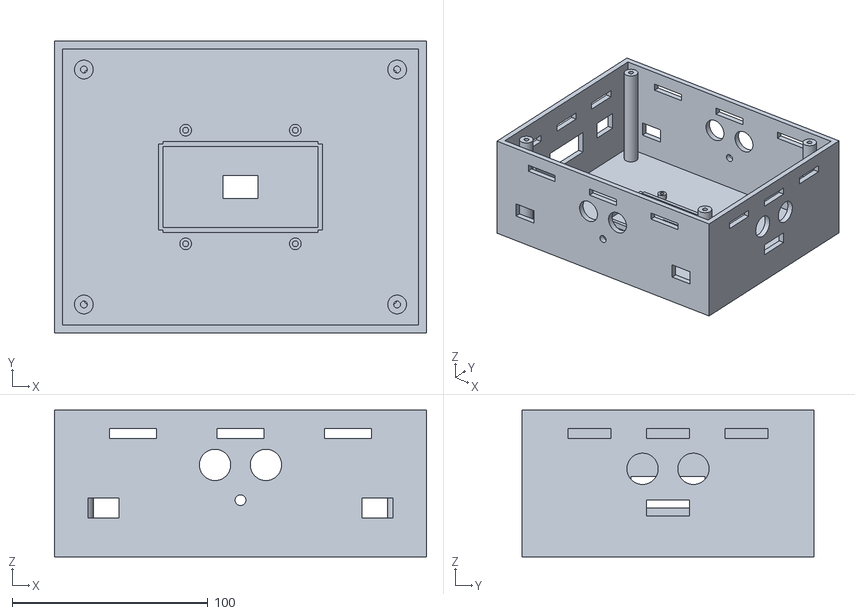
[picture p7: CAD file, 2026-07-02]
hardware/cad/主舱.stl
190.0 x 149.0 x 75.0

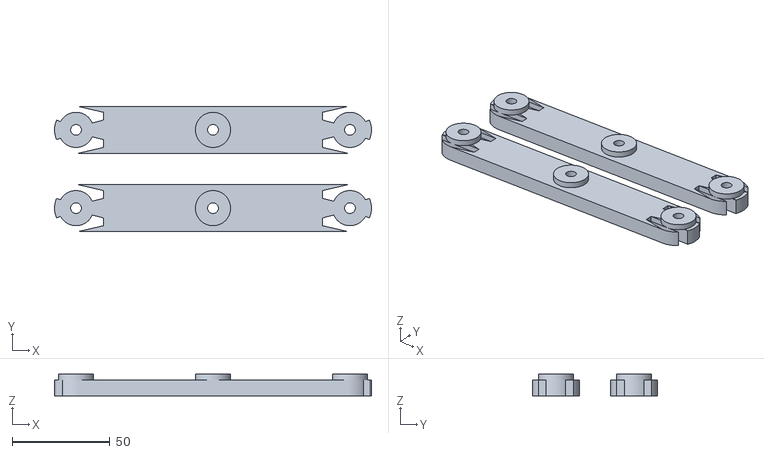
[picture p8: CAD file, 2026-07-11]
PLATE_06_BOGIE_ARMS_STACKED_FLAT_ARES_FIXED_V9.stl
162.0 x 64.0 x 11.0

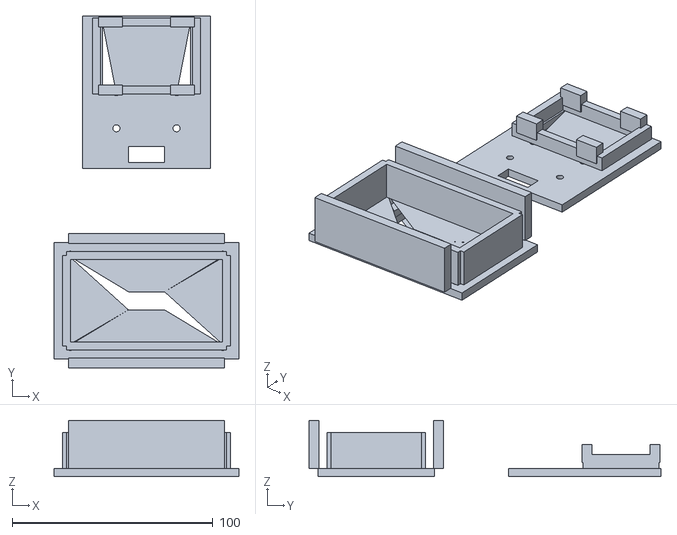
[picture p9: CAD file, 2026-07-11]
switchandcamboard.stl
92.0 x 175.5 x 28.0

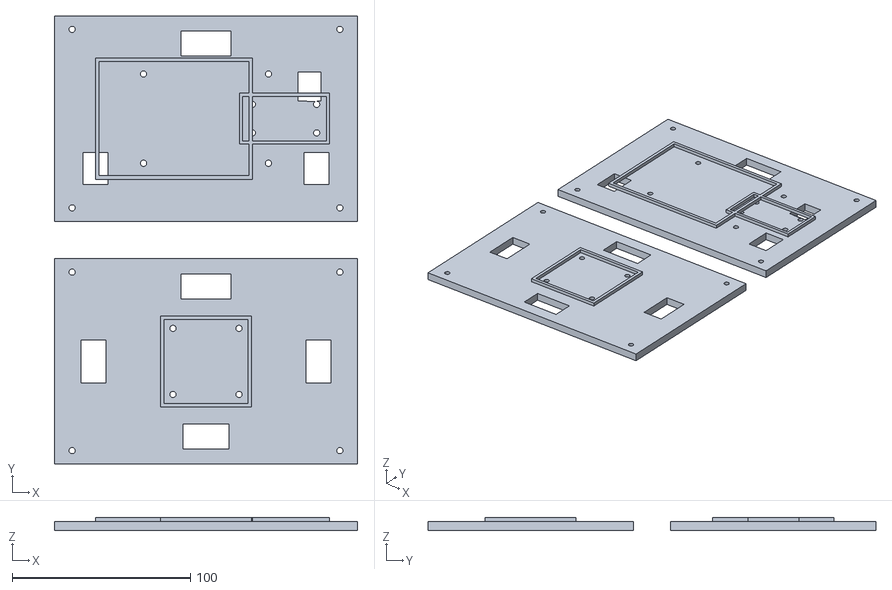
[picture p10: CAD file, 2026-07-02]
PLATE_03_F1_F2_DECKS_STACKED_FLAT_ARES_FIXED_V9.stl
170.0 x 251.0 x 7.20

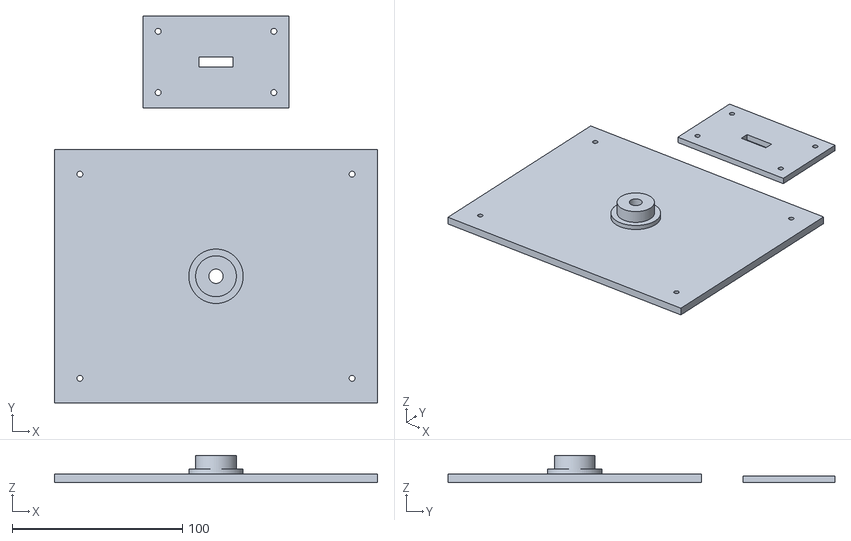
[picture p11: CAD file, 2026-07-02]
PLATE_02_TOP_LID_AND_BATTERY_DOOR_FLAT_ARES_FIXED_V9.stl
190.0 x 227.5 x 16.0

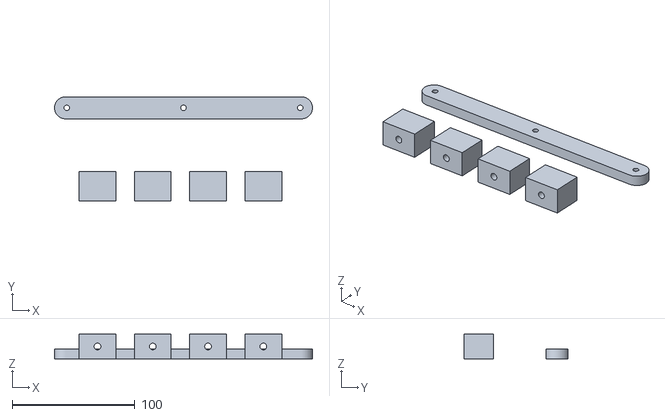
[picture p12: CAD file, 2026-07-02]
PLATE_07_PIVOT_BLOCKS_AND_BALANCE_LINK_FLAT_ARES_FIXED_V9.stl
210.0 x 85.0 x 20.0

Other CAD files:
PLATE_04_LEFT_ROCKER_DIAGONAL_FITS_256_ARES_FIXED_V9.stl

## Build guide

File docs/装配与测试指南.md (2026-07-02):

# Ares 装配与测试指南（V3）

> 依据：`docs/楼层布局.md`（四层布局）、`docs/Ares_机械减震与保温系统补充说明.md`（摇臂制作与顺序）、`docs/2米高空坠落生存与自恢复方案.md`（抗坠落件）、`hardware/Ares_V3_GPIO_Map.md`（接线唯一权威）。
> 原则：**每完成一级测试再进入下一步装配**，不要一口气装完再通电。

## 一、装配顺序

### 阶段 ①：结构（无电子件）

1. 3D 打印全部结构件（清单与参数见 `docs/下一步你要做什么.md`）。
2. 先装**一侧** Rocker-Bogie：长摇臂 + 小转向架 + 主铰链 A（Φ5）+ 二级铰链 B（Φ5）。
   螺栓 + 垫片 + 尼龙防松螺母，拧紧后回松 1/4 圈：能自由摆动、不明显旷量。**禁止热熔胶粘死铰链。**
3. 单侧验证通过后装另一侧，两侧务必等长对称。
4. 六个电机装到摆臂末端（螺丝/扎带承重，热熔胶只防滑），装轮子。
5. 摆臂与主舱可能磕碰处贴 EVA 限位缓冲；电机线预留摆动余量。
6. **结构验收**：整车放平推动，六轮全程着地；单轮压 20mm 高的垫块，其余五轮不离地。

### 阶段 ②：主舱四层（断电装配）

按 `docs/楼层布局.md`：

1. **B1**：底板铺 5mm 高密度 EVA → 电池盒居中 → 两道魔术贴勒紧（不打螺丝）。
2. **F1**：两块 L298N 贴左右边缘（若单板方案则居中靠边）、LM2596 放中缝；用 35mm 尼龙铜柱撑起上层（散热片上方留 ≥8mm）。
3. **F2**：80×60 洞洞板（ESP32 MAIN + MPU6050 焊死、排针刚性固定、MPU 水平）；四角用 **M3 硅胶减震球**连接，不用硬铜柱。
4. **天台**：柱子（视觉桅杆）过 TPU/弹簧底座装 SG90 + ESP32-CAM；碳纤维棒交叉扎成 X 穹顶（最高点须高于摄像头）；钮子开关**横装**在尾部侧板 + U 型护翼（护翼比拨杆长 ≥5mm）。
5. **配重**（50%+ 填充打印件）装在底部指定位，压低重心。

### 阶段 ③：接线（按 GPIO Map，先电源后信号）

1. 电池 → 2S BMS → 总开关 → 7.4V 总线；LM2596 调出 **5.00V**（万用表，空载与带载各测一次）再接任何板子。
2. 接 L298N（7.4V）与六电机（左组 OUT1/2、右组 OUT3/4）。
3. 接信号线：电机 IN1-4→GPIO16/17/18/19；三路超声波（**每路 Echo 经 1k/2k 分压**）；I2C（<10cm）；舵机 GPIO4；UART2（25/23 ↔ CAM 3/1）。
4. 检查单：所有 GND 共地 ✓ / Echo 都有分压 ✓ / 电机线成对绞合、比直线距离长 20% ✓ / 信号线远离电机线 ✓ / L298N 散热片不被泡棉包死 ✓。

### 阶段 ④：软件

两块板的烧录步骤见 `firmware/commander/README.md` 与 `firmware/cam/README.md`；电脑端见 `vision/README.md`。

## 二、T0–T8 分级测试（每级通过才进下一级）

| 级 | 名称 | 做法 | 通过标准 | 覆盖目标 |
| --- | --- | --- | --- | --- |
| T0 | 桌面单件 | 面包板上逐件点亮：ESP32 烧录、MPU 读数、单路超声波、舵机扫动、CAM 出图 | 每件工作正常 | — |
| T1 | 架空联调 | **车轮离地**上电，dashboard 连接：WASD 前后左右、E-STOP、AUTO 挥手触发避障动作 | 方向全对；E-STOP 立即锁死；L298N 连转 5 分钟不烫手（>60℃ 需换双板） | 1 |
| T2 | 直线与速度标定 | 地面 5m 直线跑 3 次；卷尺量横向偏移；秒表测速度 | 偏移 ≤ 30cm（调 `YAW_KP/KD` 后复测）；把实测 cm/s 回填 `CM_PER_SEC_CRUISE` | 2 |
| T3 | 避障 | AUTO 模式，前方 1m 放纸箱，左右不对称留口 | 距箱 ~20cm 停车，转向空旷侧通过，10 次 ≥8 次成功 | 5 |
| T4 | 爬坡 | 木板逐步垫高 10°→15°→20°→25°（防滑面） | 25° 能匀速爬完 1m 不溜坡不翻车（不行→换 1:90/1:120 电机或加大轮纹） | 3 |
| T5 | 拍摄任务 | dashboard 点全景/伪 3D；电脑跑 receive_server | 全景 7 张全收到且能拼接；伪 3D 两张视差明显、能出红蓝图 | 10.1/10.2 |
| T6 | 休眠唤醒 | 演示按钮或遮光入睡；亮光/定时唤醒 | 入睡后电机断电；唤醒后 wake_count +1；80 次触发冲刺模式（可临时把 `WAKE_LIMIT` 改小验证） | 8 |
| T7 | 建图 | 2×3m 围出区域，AUTO 巡航 3 分钟 + telemetry_logger 录制 | plot_map 出图，轨迹与实际路线拓扑一致、障碍点贴近边界 | 10.3 |
| T8 | 跌落（最后做！） | 检查全部防护件到位（软胎/EVA/减震球/穹顶/桅杆弹性/开关护翼）→ 30cm→1m→2m 逐级跌落到**草地或缓冲垫** | 每级落地后遥测正常、可继续行驶；倒扣时穹顶+低重心能翻正（必要时 MPU 检测翻转后轮子助翻） | 4、11 |

安全：T1 前必须架空；T4/T8 旁边随时准备按 E-STOP；T8 全程人员离开落点，逐级进行，任何一级失败先修复再继续，**不要直接上 2m**。

## 三、温度演示（-20°~50° 目标的模型化验收）

1. 装保温盒（EVA 夹层，L298N/LM2596 留散热通道）。
2. 若装了 DS18B20（`ENABLE_DS18B20 1`）：冰袋贴盒外侧 → 遥测 `thermal` 依次出现 COLD_START/COLD_SLEEP；吹风机远距离加热 → HOT_LIMIT/THERMAL_PAUSE，随后自动恢复 NORMAL。全程人工看护，**锂电池不进冰箱**。
3. 未装传感器：以保温结构 + `firmware/commander/thermal.h` 的状态机代码作为设计演示。

## 四、验收总表（对应 AGENTS.md 11 项目标）

| 目标 | 验收方式 | 对应测试 |
| --- | --- | --- |
| 1 六轮差速 | 架空四方向 + 原地转 | T1 |
| 2 5m 直线 | 偏移 ≤30cm | T2 |
| 3 25° 爬坡 | 斜板实测 | T4 |
| 4 2m 跌落 | 逐级跌落后功能正常 | T8 |
| 5 自动驾驶 | 避障成功率 ≥80% | T3 |
| 6 机械臂 | 第二阶段（结构预留） | — |
| 7 ≤$150 | 按 `hardware/Ares_BOM.md` 核算实际支出 | — |
| 8 100 天+每日回传 | 休眠计数模拟 + telemetry_logger 日志 | T6 |
| 9 -20°~50° | 保温盒 + 热控状态机演示 | 三 |
| 10 拍摄与地图 | 30 张 3D、10 张全景、1 张地图 | T5/T7 |
| 11 Rocker-Bogie | 单轮越障五轮着地 | 阶段① |

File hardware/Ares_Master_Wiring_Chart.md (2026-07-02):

# PROJECT ARES V2.2 - MASTER WIRING CHART

Read First:

- `[ 5V BUS ]`: This means tie the wire to your central 5V power line (Output of the LM2596).
- `[ 7.4V BUS ]`: This means tie the wire to your raw battery power line (After the switch).
- `[ GND BUS ]`: This means tie the wire to your common Ground line (All GNDs must connect together!).

### 1. POWER SYSTEM (The Heart)

Wire this section first using thicker wires to handle the current.

| Source Component | Source Pin | Wire Color | Destination Component | Destination Pin / GPIO | Function |
| --- | --- | --- | --- | --- | --- |
| Solar Panels (x3) | + (Positive) | 🔴 Red | 2S BMS Module | IN+ | Solar Charging Power |
| Solar Panels (x3) | - (Negative) | ⚫ Black | 2S BMS Module | IN- | Solar Ground |
| 18650 Battery Bay | + (7.4V) | 🔴 Red | 2S BMS Module | B+ | Battery Positive |
| 18650 Battery Bay | - (GND) | ⚫ Black | 2S BMS Module | B- | Battery Negative |
| 2S BMS Module | P+ (Out) | 🔴 Red | Master Switch | Pin 1 | Main Power Line |
| 2S BMS Module | P- (GND) | ⚫ Black | [ GND BUS ] | Common GND | Main System Ground |
| Master Switch | Pin 2 | 🔴 Red | [ 7.4V BUS ] | Common 7.4V | Switched Raw Power |
| [ 7.4V BUS ] | Common 7.4V | 🔴 Red | LM2596 Buck | IN+ | Feed power to Step-Down |
| [ GND BUS ] | Common GND | ⚫ Black | LM2596 Buck | IN- | Ground for Step-Down |
| LM2596 Buck | OUT+ (5V) | 🟠 Orange | [ 5V BUS ] | Common 5V | Provides Safe 5V Power |
| LM2596 Buck | OUT- (GND) | ⚫ Black | [ GND BUS ] | Common GND | Ground |

### 2. MOTOR CONTROL (The Legs)

Controls the 6-wheel skid steering.

| Source Component | Source Pin | Wire Color | Destination Component | Destination Pin / GPIO | Function |
| --- | --- | --- | --- | --- | --- |
| L298N (LEFT) | 12V IN | 🔴 Red | [ 7.4V BUS ] | Common 7.4V | Motor Power Left |
| L298N (LEFT) | GND | ⚫ Black | [ GND BUS ] | Common GND | Motor Ground Left |
| ESP32 (Main) | GPIO 32 | 🟣 Purple | L298N (LEFT) | IN1 | Left Forward Signal |
| ESP32 (Main) | GPIO 33 | 🟣 Purple | L298N (LEFT) | IN2 | Left Reverse Signal |
| Left Motors (x3) | Terminal 1 | 🟤 Brown | L298N (LEFT) | OUT1 | Power to Left Wheels |
| Left Motors (x3) | Terminal 2 | 🟤 Brown | L298N (LEFT) | OUT2 | Power to Left Wheels |
| L298N (RIGHT) | 12V IN | 🔴 Red | [ 7.4V BUS ] | Common 7.4V | Motor Power Right |
| L298N (RIGHT) | GND | ⚫ Black | [ GND BUS ] | Common GND | Motor Ground Right |
| ESP32 (Main) | GPIO 25 | 🟣 Purple | L298N (RIGHT) | IN3 | Right Forward Signal |
| ESP32 (Main) | GPIO 26 | 🟣 Purple | L298N (RIGHT) | IN4 | Right Reverse Signal |
| Right Motors (x3) | Terminal 1 | 🟤 Brown | L298N (RIGHT) | OUT3 | Power to Right Wheels |
| Right Motors (x3) | Terminal 2 | 🟤 Brown | L298N (RIGHT) | OUT4 | Power to Right Wheels |

### 3. SENSORS (The Eyes & Ears)

Powers the Gyroscope and the Radar Array.

| Source Component | Source Pin | Wire Color | Destination Component | Destination Pin / GPIO | Function |
| --- | --- | --- | --- | --- | --- |
| MPU6050 (Gyro) | VCC | 🟠 Orange | [ 5V BUS ] | Common 5V | Sensor Power |
| MPU6050 (Gyro) | GND | ⚫ Black | [ GND BUS ] | Common GND | Sensor Ground |
| MPU6050 (Gyro) | SDA | 🔵 Blue | ESP32 (Main) | GPIO 21 | I2C Data Line |
| MPU6050 (Gyro) | SCL | 🔵 Blue | ESP32 (Main) | GPIO 22 | I2C Clock Line |
| HC-SR04 (Radars) | VCC | 🟠 Orange | [ 5V BUS ] | Common 5V | Radar Power |
| HC-SR04 (Radars) | GND | ⚫ Black | [ GND BUS ] | Common GND | Radar Ground |
| HC-SR04 (Radars) | Trig | 🟢 Green | ESP32 (Main) | GPIO 19 | Radar Pulse Out |
| HC-SR04 (Radars) | Echo | 🟢 Green | ESP32 (Main) | GPIO 18 | Radar Echo Return |

> Note: Wire all 3 HC-SR04 sensors in parallel to the exact same pins. The ESP32 will read them as one giant front bumper.

### 4. DEPLOYABLE SERVOS & 3D CAMERA (The Advanced Payload)

Powers the folding solar wings, the 3D scanning servo, and the camera communication.

| Source Component | Source Pin | Wire Color | Destination Component | Destination Pin / GPIO | Function |
| --- | --- | --- | --- | --- | --- |
| Left Wing Servo | VCC / GND | 🟠/⚫ | [ 5V & GND BUS] | Common Buses | Servo Power |
| Left Wing Servo | PWM Signal | 🟡 Yellow | ESP32 (Main) | GPIO 13 | Angle Control |
| Right Wing Servo | VCC / GND | 🟠/⚫ | [ 5V & GND BUS] | Common Buses | Servo Power |
| Right Wing Servo | PWM Signal | 🟡 Yellow | ESP32 (Main) | GPIO 12 | Angle Control |
| Scanner Pan Servo | VCC / GND | 🟠/⚫ | [ 5V & GND BUS] | Common Buses | Servo Power |
| Scanner Pan Servo | PWM Signal | 🟡 Yellow | ESP32 (Main) | GPIO 4 | Pan Control (Sweep) |
| ESP32-CAM (Cam) | 5V | 🟠 Orange | [ 5V BUS ] | Common 5V | Camera Power |
| ESP32-CAM (Cam) | GND | ⚫ Black | [ GND BUS ] | Common GND | Camera Ground |
| ESP32-CAM (Cam) | TX | 🟣 Magenta | ESP32 (Main) | GPIO 16 (RX2) | Data TO Main Brain |
| ESP32-CAM (Cam) | RX | 🟣 Magenta | ESP32 (Main) | GPIO 17 (TX2) | Commands FROM Main |

### 5. MAIN BRAIN POWER

| Source Component | Source Pin | Wire Color | Destination Component | Destination Pin / GPIO | Function |
| --- | --- | --- | --- | --- | --- |
| ESP32 (Main) | VIN or 5V | 🟠 Orange | [ 5V BUS ] | Common 5V | Powers the Main Brain |
| ESP32 (Main) | GND | ⚫ Black | [ GND BUS ] | Common GND | Brain Ground |

### 6. OPTIONAL THERMAL MONITORING & INSULATION NOTES

Passive insulation has no electrical wiring, but the optional temperature sensor can be wired as follows.

| Source Component | Source Pin | Wire Color | Destination Component | Destination Pin / GPIO | Function |
| --- | --- | --- | --- | --- | --- |
| DS18B20 Temp Sensor | VCC | 🟠 Orange | ESP32 (Main) | 3V3 | Sensor Power, use 3.3V not 5V |
| DS18B20 Temp Sensor | GND | ⚫ Black | [ GND BUS ] | Common GND | Sensor Ground |
| DS18B20 Temp Sensor | DATA | 🟡 Yellow | ESP32 (Main) | GPIO 27 | OneWire Temperature Data |
| 4.7kΩ Resistor | One End | 🟡 Yellow | ESP32 (Main) | GPIO 27 | Pull-up for DS18B20 DATA |
| 4.7kΩ Resistor | Other End | 🟠 Orange | ESP32 (Main) | 3V3 | Pull-up to 3.3V |

Thermal construction notes:

- Put the ESP32, battery bay, and camera-related connectors inside a central insulated electronics box.
- Use EVA foam, thin sponge, foam board, or corrugated cardboard as insulation.
- Do not let aluminum foil, metallic tape, screws, or wire ends touch battery terminals or PCB solder joints.
- Do not fully wrap the L298N heat sink or LM2596 in foam during motor tests; they need a path to release heat.
- No active heater is included in the baseline wiring. If a heater is added later, it must have independent protection, a fuse, temperature control, and explicit user approval.

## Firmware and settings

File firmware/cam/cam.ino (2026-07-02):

// ============================================================
// PROJECT ARES - ESP32-CAM 视觉从板固件（AI-Thinker）
//
// 职责（docs/Ares_Control_Architecture.md §7.2）：
//   1. UART 从协议：应答 Commander 的 PING / CAPTURE STILL / STATUS? / STREAM
//   2. 拍照后 HTTP POST 上传到电脑端 vision/receive_server.py
//   3. /stream 提供 MJPEG 实时流（dashboard 视频窗口直接连）
//
// ⚠ 本板与 Commander 的链路复用烧录串口 U0（GPIO1/3）：
//   烧录或接串口监视器前，必须先断开与 Commander GPIO25/23 的两根线！
// ⚠ 调试输出以 "# " 开头，Commander 会忽略这类行。
//
// 烧录前：改 config.h 的 WIFI_SSID / WIFI_PASSWORD / PC_HOST
// 无需第三方库（esp_camera / WebServer / HTTPClient 都在 ESP32 核心里）
// ============================================================
#include <WiFi.h>
#include <WebServer.h>
#include <HTTPClient.h>
#include "esp_camera.h"
#include "config.h"
#include "camera_pins.h"

WebServer server(HTTP_PORT);
bool streamEnabled = true;   // STREAM START/STOP 可开关
bool camReady = false;
bool busy = false;

char rxBuf[96];
size_t rxLen = 0;

// ---------------- 相机初始化 ----------------
bool cameraInit() {
  camera_config_t c = {};
  c.ledc_channel = LEDC_CHANNEL_0;
  c.ledc_timer   = LEDC_TIMER_0;
  c.pin_d0 = Y2_GPIO_NUM;  c.pin_d1 = Y3_GPIO_NUM;
  c.pin_d2 = Y4_GPIO_NUM;  c.pin_d3 = Y5_GPIO_NUM;
  c.pin_d4 = Y6_GPIO_NUM;  c.pin_d5 = Y7_GPIO_NUM;
  c.pin_d6 = Y8_GPIO_NUM;  c.pin_d7 = Y9_GPIO_NUM;
  c.pin_xclk = XCLK_GPIO_NUM;
  c.pin_pclk = PCLK_GPIO_NUM;
  c.pin_vsync = VSYNC_GPIO_NUM;
  c.pin_href = HREF_GPIO_NUM;
  c.pin_sccb_sda = SIOD_GPIO_NUM;
  c.pin_sccb_scl = SIOC_GPIO_NUM;
  c.pin_pwdn = PWDN_GPIO_NUM;
  c.pin_reset = RESET_GPIO_NUM;
  c.xclk_freq_hz = 20000000;
  c.pixel_format = PIXFORMAT_JPEG;
  if (psramFound()) {
    c.frame_size = FRAMESIZE_UXGA;      // 1600x1200
    c.jpeg_quality = JPEG_QUALITY;
    c.fb_count = 2;
    c.fb_location = CAMERA_FB_IN_PSRAM;
  } else {
    c.frame_size = FRAMESIZE_SVGA;      // 800x600
    c.jpeg_quality = JPEG_QUALITY + 4;
    c.fb_count = 1;
    c.fb_location = CAMERA_FB_IN_DRAM;
  }
  return esp_camera_init(&c) == ESP_OK;
}

// ---------------- 拍照并上传到电脑 ----------------
// 成功返回 true。照片以 name 命名存到电脑 vision/incoming/<name>.jpg
bool captureAndUpload(const char* name) {
  if (!camReady) return false;
  busy = true;
#if USE_FLASH_LED
  digitalWrite(FLASH_LED_GPIO, HIGH);
  delay(60);
#endif
  camera_fb_t* fb = esp_camera_fb_get();
#if USE_FLASH_LED
  digitalWrite(FLASH_LED_GPIO, LOW);
#endif
  if (!fb) { busy = false; return false; }

  bool ok = false;
  if (WiFi.status() == WL_CONNECTED) {
    HTTPClient http;
    char url[160];
    snprintf(url, sizeof(url), "http://%s:%d/upload?name=%s", PC_HOST, PC_PORT, name);
    if (http.begin(url)) {
      http.addHeader("Content-Type", "image/jpeg");
      http.setTimeout(6000);
      int code = http.POST(fb->buf, fb->len);
      ok = (code >= 200 && code < 300);
      http.end();
    }
  }
  esp_camera_fb_return(fb);
  busy = false;
  return ok;
}

// ---------------- UART 从协议 ----------------
void handleLine(char* line) {
  // 去掉行尾空白
  size_t n = strlen(line);
  while (n && (line[n-1] == ' ' || line[n-1] == '\t')) line[--n] = 0;
  if (n == 0) return;

  if (strcmp(line, "PING") == 0) {
    Serial.print("ACK PING\n");

  } else if (strncmp(line, "CAPTURE STILL ", 14) == 0) {
    const char* name = line + 14;
    if (busy) { Serial.print("BUSY\n"); return; }
    Serial.printf("ACK CAPTURE %s\n", name);
    if (captureAndUpload(name)) Serial.printf("DONE CAPTURE %s\n", name);
    else                        Serial.print("ERR UPLOAD_FAIL\n");

  } else if (strcmp(line, "STREAM START") == 0) {
    streamEnabled = true;  Serial.print("ACK STREAM START\n");
  } else if (strcmp(line, "STREAM STOP") == 0) {
    streamEnabled = false; Serial.print("ACK STREAM STOP\n");

  } else if (strcmp(line, "STATUS?") == 0) {
    Serial.printf("STATUS %s\n", busy ? "BUSY" : (camReady ? "READY" : "ERR"));
  }
  // 其他行（包括 Commander 误收的调试行）一律忽略
}

void uartPoll() {
  while (Serial.available()) {
    char ch = (char)Serial.read();
    if (ch == '\r') continue;
    if (ch == '\n') { rxBuf[rxLen] = 0; handleLine(rxBuf); rxLen = 0; }
    else if (rxLen < sizeof(rxBuf) - 1) rxBuf[rxLen++] = ch;
  }
}

// ---------------- HTTP：信息页 / 手动拍照 / MJPEG 流 ----------------
void handleRoot() {
  char msg[240];
  snprintf(msg, sizeof(msg),
           "PROJECT ARES CAM\ncam:%s stream:%s\nPOST target: http://%s:%d/upload\n"
           "endpoints: /stream  /capture?name=test\n",
           camReady ? "READY" : "ERR", streamEnabled ? "on" : "off", PC_HOST, PC_PORT);
  server.send(200, "text/plain", msg);
}

void handleCapture() {
  String name = server.hasArg("name") ? server.arg("name") : "manual";
  bool ok = captureAndUpload(name.c_str());
  server.send(ok ? 200 : 500, "text/plain", ok ? "DONE" : "ERR");
}

// MJPEG：占住当前连接持续推帧；期间仍轮询 UART，拍照命令可插队
void handleStream() {
  WiFiClient client = server.client();
  client.print("HTTP/1.1 200 OK\r\n"
               "Content-Type: multipart/x-mixed-replace; boundary=frame\r\n"
               "Access-Control-Allow-Origin: *\r\n\r\n");
  while (client.connected() && streamEnabled) {
    camera_fb_t* fb = esp_camera_fb_get();
    if (!fb) break;
    client.printf("--frame\r\nContent-Type: image/jpeg\r\nContent-Length: %u\r\n\r\n",
                  (unsigned)fb->len);
    client.write(fb->buf, fb->len);
    client.print("\r\n");
    esp_camera_fb_return(fb);
    uartPoll();               // 直播时也响应 Commander
    delay(50);                // ~15fps 上限，给 Wi-Fi 留带宽
  }
  client.stop();
}

// ---------------- 主流程 ----------------
void setup() {
  pinMode(STATUS_LED_GPIO, OUTPUT);
  digitalWrite(STATUS_LED_GPIO, LOW);      // 亮 = 启动中
#if USE_FLASH_LED
  pinMode(FLASH_LED_GPIO, OUTPUT);
  digitalWrite(FLASH_LED_GPIO, LOW);
#endif

  Serial.begin(LINK_BAUD);
  Serial.print("# ARES CAM boot\n");

  camReady = cameraInit();
  Serial.printf("# camera %s, psram %s\n", camReady ? "ok" : "FAIL",
                psramFound() ? "yes" : "no");

  WiFi.mode(WIFI_STA);
  WiFi.setHostname(HOSTNAME);
  WiFi.begin(WIFI_SSID, WIFI_PASSWORD);
  for (int i = 0; i < 30 && WiFi.status() != WL_CONNECTED; i++) {
    delay(500);
    digitalWrite(STATUS_LED_GPIO, i % 2);  // 闪烁 = 连网中
  }
  if (WiFi.status() == WL_CONNECTED) {
    Serial.printf("# ip %s (dashboard 视频地址填这个)\n",
                  WiFi.localIP().toString().c_str());
    digitalWrite(STATUS_LED_GPIO, HIGH);   // 灭 = 就绪（低电平灯）
  } else {
    Serial.print("# wifi FAIL\n");
  }

  server.on("/", handleRoot);
  server.on("/capture", handleCapture);
  server.on("/stream", handleStream);
  server.begin();
}

void loop() {
  server.handleClient();
  uartPoll();
  delay(2);
}

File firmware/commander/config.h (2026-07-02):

// ============================================================
// PROJECT ARES - Commander ESP32 全车配置
// 引脚与 hardware/Ares_V3_GPIO_Map.md 保持一致；改引脚先改那份文档
// ============================================================
#pragma once

// ---------- Wi-Fi（烧录前必填） ----------
#define WIFI_SSID       "YOUR_WIFI_SSID"      // 改成你的热点/路由器名
#define WIFI_PASSWORD   "YOUR_WIFI_PASSWORD"  // 改成密码
#define WS_PORT         81                    // WebSocket 服务端口（dashboard 连这里）
#define HOSTNAME        "ares-commander"

// ---------- 功能开关（未接的可选件保持 0，不影响编译运行） ----------
#define ENABLE_CAMLINK  1   // UART2 连接 ESP32-CAM（断开联调时可置 0）
#define ENABLE_DS18B20  0   // 舱内温度传感器（需安装 OneWire + DallasTemperature 库）
#define ENABLE_LDR      0   // 光敏模块（休眠唤醒演示）
#define ENABLE_VBAT     0   // 电池电压分压检测（GPIO36）

// ---------- 电机（单 L298N：IN1-IN4，直接 PWM 调速） ----------
#define PIN_ML_FWD      16  // 左侧 3 电机 正转（L298N IN1）
#define PIN_ML_REV      17  // 左侧 3 电机 反转（L298N IN2）
#define PIN_MR_FWD      18  // 右侧 3 电机 正转（L298N IN3）
#define PIN_MR_REV      19  // 右侧 3 电机 反转（L298N IN4）
#define MOTOR_PWM_FREQ  1000   // Hz，L298N(BJT) 适用
#define MOTOR_PWM_BITS  10     // 分辨率 0-1023
#define MOTOR_MAX_PCT   90     // 最高占空比限幅（保护单 L298N）
#define MOTOR_RAMP_PCT  5      // 软启动：每个控制周期最多变化 5%
#define MOTOR_TICK_MS   20     // 控制周期

// ---------- 超声波（3 路独立，F/L/R 若与实车不符只改这里） ----------
#define PIN_SONAR_F_TRIG 13
#define PIN_SONAR_F_ECHO 14   // 所有 Echo 必须经 1k/2k 分压！
#define PIN_SONAR_L_TRIG 27
#define PIN_SONAR_L_ECHO 26
#define PIN_SONAR_R_TRIG 33
#define PIN_SONAR_R_ECHO 32
#define SONAR_INTERVAL_MS 40   // 轮询间隔（三路防串扰）
#define SONAR_MAX_CM      300

// ---------- IMU（MPU6050，I2C） ----------
// 注意：手绘线路图标注 SCL-D21/SDA-D22 与此相反；若按手绘接线，把下面两行互换
#define PIN_I2C_SDA     21
#define PIN_I2C_SCL     22
#define IMU_CALIB_MS    2000   // 上电静置标定时长（期间别动车）

// ---------- 直线保持 PID（先只调 P，再加 D） ----------
#define YAW_KP          0.030f  // 每偏 1° 差速修正量（0-1 油门单位）
#define YAW_KI          0.000f
#define YAW_KD          0.008f
#define YAW_CORR_MAX    0.35f   // 差速修正限幅

// ---------- 自动驾驶（AUTO-L2 三向感知） ----------
#define OBSTACLE_STOP_CM   20   // 前方低于此距离停车选路
#define AUTO_CRUISE        0.55f // 巡航油门 0-1
#define AVOID_BACK_MS      400  // 遇障后退时长
#define AVOID_TURN_MS      600  // 原地转向时长
#define CM_PER_SEC_CRUISE  15.0f // 巡航速度标定值（T2 测试后按实测改！）
#define STEREO_ADVANCE_CM  6.0f  // 伪 3D 两拍之间直线前进距离（完整指南步骤 4）

// ---------- 云台舵机（SG90，0-180°） ----------
#define PIN_SERVO_PAN   4
#define PAN_STEP_DEG    30     // 全景每步角度
#define PAN_SETTLE_MS   600    // 舵机到位等待

// ---------- 相机链路（UART2，115200 8N1） ----------
#define PIN_CAM_TX      25   // -> ESP32-CAM GPIO3 (U0RXD)
#define PIN_CAM_RX      23   // <- ESP32-CAM GPIO1 (U0TXD)
#define CAM_BAUD        115200
#define CAM_ACK_TIMEOUT_MS   1500
#define CAM_DONE_TIMEOUT_MS  8000  // 拍照+上传较慢
#define CAM_PING_INTERVAL_MS 3000

// ---------- 遥测 / 心跳 ----------
#define TELEMETRY_MS         200   // 5Hz
#define HEARTBEAT_TIMEOUT_MS 1500  // TELEOP 心跳超时 -> 停车

// ---------- 休眠与"100 天生存"模拟 ----------
#define WAKE_LIMIT           80    // 唤醒次数达到后触发 Final_Mission_Mode
#define SLEEP_TIMER_WAKE_S   30    // 无 LDR 时的定时唤醒（演示用）
#define LDR_DARK_THRESHOLD   500   // analogRead(0-4095) 低于视为黑夜
#define LDR_DARK_HOLD_MS     10000 // 持续黑暗超过此时长才入睡
#define PIN_LDR_AO           34
#define PIN_LDR_DO           35
#define PIN_DS18B20          15
#define PIN_VBAT             36
#define VBAT_DIVIDER         4.03f // (100k+33k)/33k，按实测微调

// ---------- 热控阈值（docs/Ares_机械减震与保温系统补充说明.md 3.5.4） ----------
#define T_COLD_SLEEP    -10.0f
#define T_COLD_START      0.0f
#define T_HOT_LIMIT      45.0f
#define T_THERMAL_PAUSE  50.0f
#define HOT_LIMIT_PCT    60    // HOT_LIMIT 状态下的占空比上限
#define COLD_START_PCT   40    // COLD_START 状态下的占空比上限

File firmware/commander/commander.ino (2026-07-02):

// ============================================================
// PROJECT ARES - Commander ESP32 主控固件
//
// 职责（docs/Ares_Control_Architecture.md §7.1）：
//   电机差速 + 软启动 | MPU6050 直线保持 | 三向超声波避障(AUTO-L2)
//   模式状态机 IDLE/AUTO/TELEOP-PC/CAPTURE/E-STOP/SLEEP
//   热控五态机 | 休眠唤醒 + Final_Mission_Mode | 云台舵机
//   UART2 指挥 ESP32-CAM | WebSocket 遥测/遥控（dashboard/index.html）
//
// 烧录前：改 config.h 里的 WIFI_SSID / WIFI_PASSWORD
// 需要的库：ArduinoJson(>=7)、WebSockets(links2004)，见本目录 README.md
// 安全：首次调试必须架空车轮！
// ============================================================
#include "config.h"
#include "state.h"
#include "motors.h"
#include "imu.h"
#include "sonar.h"
#include "thermal.h"
#include "powersleep.h"
#include "camlink.h"
#include "mission.h"
#include "comms.h"

// ---- 全局单例（各模块 extern 引用） ----
RoverState rover;
MotorsCtl  motors;
ImuCtl     imu;
SonarCtl   sonar;
ThermalCtl thermal;
PowerCtl   power;
CamLink    camlink;
MissionCtl mission;
CommsCtl   comms;

void setup() {
  Serial.begin(115200);
  delay(200);
  Serial.println("\n==== PROJECT ARES Commander ====");

  motors.begin();          // 先确保电机输出为 0
  power.begin();           // 唤醒计数（RTC 内存）
  Serial.printf("[boot] wake_count=%lu final_mission=%d\n",
                (unsigned long)rover.wakeCount, rover.finalMission);

  Serial.println("[boot] IMU 标定中，请保持整车静止 2 秒...");
  if (!imu.begin()) {
    Serial.println("[boot] MPU6050 初始化失败！检查 I2C 接线（或在 config.h 互换 SDA/SCL）");
    commsAlert("ERROR", "IMU_FAIL");   // WiFi 未起时只打印串口
  }

  sonar.begin();
  thermal.begin();
  camlink.begin();
  mission.begin();
  comms.begin();           // 最后连 WiFi，串口会打印 IP

  // 最终任务模式：唤醒次数到 80 次后自动全速执行拍摄任务（步骤 5"冲刺模式"）
  if (rover.finalMission) {
    commsAlert("WARN", "FINAL_MISSION_MODE");
    missionSetMode(MODE_AUTO, "final_mission");
  }
  Serial.println("[boot] ready.");
}

void loop() {
  imu.tick();        // 姿态积分（尽量高频）
  sonar.tick();      // 三向测距轮询
  thermal.tick();    // 热控状态机
  power.tick();      // 电压/光照采样与入睡判断
  camlink.tick();    // 相机链路收发
  mission.tick();    // 模式与任务状态机（产生驱动指令）
  motors.tick();     // 软启动斜坡输出
  comms.tick();      // WebSocket 收发 + 5Hz 遥测
}

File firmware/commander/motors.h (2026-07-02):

// ============================================================
// 电机驱动：单 L298N，IN1-IN4 直接输出 LEDC PWM 实现调速
// 差速/坦克转向 + 软启动斜坡 + 占空比限幅（保护驱动板）
// 兼容 arduino-esp32 核心 2.x 与 3.x 的 LEDC API
// ============================================================
#pragma once
#include <Arduino.h>
#include "config.h"
#include "state.h"

#ifndef ESP_ARDUINO_VERSION_MAJOR
#define ESP_ARDUINO_VERSION_MAJOR 2
#endif

static const int MOTOR_DUTY_MAX = (1 << MOTOR_PWM_BITS) - 1;

// core 2.x 需要手动分配 LEDC 通道；core 3.x 按引脚自动管理
#if ESP_ARDUINO_VERSION_MAJOR >= 3
inline void pwmSetup(int pin, int /*ch*/) { ledcAttach(pin, MOTOR_PWM_FREQ, MOTOR_PWM_BITS); }
inline void pwmWrite(int pin, int /*ch*/, uint32_t duty) { ledcWrite(pin, duty); }
#else
inline void pwmSetup(int pin, int ch) { ledcSetup(ch, MOTOR_PWM_FREQ, MOTOR_PWM_BITS); ledcAttachPin(pin, ch); }
inline void pwmWrite(int /*pin*/, int ch, uint32_t duty) { ledcWrite(ch, duty); }
#endif

struct MotorsCtl {
  // 目标与当前占空比，单位：百分比 -100..100（正=前进）
  float targetL = 0, targetR = 0;
  float curL = 0, curR = 0;
  int   dutyCapPct = MOTOR_MAX_PCT;   // 热控可以进一步压低
  uint32_t lastTickMs = 0;

  void begin() {
    pwmSetup(PIN_ML_FWD, 0); pwmSetup(PIN_ML_REV, 1);
    pwmSetup(PIN_MR_FWD, 2); pwmSetup(PIN_MR_REV, 3);
    applyRaw(0, 0);
  }

  // throttle/turn ∈ [-1,1]；turn>0 右转（左轮加速、右轮减速）
  void setDrive(float throttle, float turn) {
    throttle = constrain(throttle, -1.0f, 1.0f);
    turn     = constrain(turn,     -1.0f, 1.0f);
    float l = throttle + turn, r = throttle - turn;
    float m = max(fabsf(l), fabsf(r));
    if (m > 1.0f) { l /= m; r /= m; }          // 归一化防溢出
    targetL = l * 100.0f; targetR = r * 100.0f;
  }

  void stop() { targetL = targetR = 0; }

  // E-STOP：越过斜坡立即切断
  void hardStop() {
    targetL = targetR = curL = curR = 0;
    applyRaw(0, 0);
  }

  void tick() {
    uint32_t now = millis();
    if (now - lastTickMs < MOTOR_TICK_MS) return;
    lastTickMs = now;
    curL = ramp(curL, targetL);
    curR = ramp(curR, targetR);
    applyRaw(curL, curR);
  }

private:
  float ramp(float cur, float tgt) {
    float step = MOTOR_RAMP_PCT;
    if (tgt > cur) cur = min(cur + step, tgt);
    else if (tgt < cur) cur = max(cur - step, tgt);
    return cur;
  }

  void applyRaw(float lPct, float rPct) {
    float cap = (float)dutyCapPct;
    lPct = constrain(lPct, -cap, cap);
    rPct = constrain(rPct, -cap, cap);
    writeSide(lPct, PIN_ML_FWD, 0, PIN_ML_REV, 1);
    writeSide(rPct, PIN_MR_FWD, 2, PIN_MR_REV, 3);
  }

  void writeSide(float pct, int pinF, int chF, int pinR, int chR) {
    uint32_t duty = (uint32_t)(fabsf(pct) / 100.0f * MOTOR_DUTY_MAX);
    if (pct >= 0) { pwmWrite(pinF, chF, duty); pwmWrite(pinR, chR, 0); }
    else          { pwmWrite(pinF, chF, 0);    pwmWrite(pinR, chR, duty); }
  }
};

extern MotorsCtl motors;

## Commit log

2026-07-02 重组仓库目录：文档入 docs/，硬件资料入 hardware/（cad/drawings）
    根目录只保留 AGENTS.md 与 LICENSE，为 firmware/、vision/、dashboard/
    等新增代码目录腾出清晰结构。所有文件仅移动，内容未改。
    Claude-Session: https://claude.ai/code/session_013EjBnVrGEd7jLDMMy4NR9m
    [主舱.stl, 摆臂（需打印4份）.stl, 柱子.stl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]
2026-07-02 文档基线切换到 V3：重写 AGENTS.md，新增引脚表、决策记录与装配测试指南
    - AGENTS.md：基线改为 V3 手绘版（取消太阳能、3D 打印四层主舱、三向
    独立超声波、单 L298N、电机引脚 D16-D19），修正全部失效文件引用，
    补充旧引用映射表与新目录结构
    - README.md：项目总览、目录导航、三条上手路径
    - hardware/Ares_V3_GPIO_Map.md：全车唯一权威引脚表（重建散佚的
    GPIO Map），含 Echo 分压、单 L298N 电流风险与双板备选
    - docs/Ares_V3_决策记录.md：13 条两代方案冲突裁决（依据/推断/待确认）
    - docs/装配与测试指南.md：装配四阶段 + T0-T8 分级验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
2026-07-02 新增全套软件：双板固件、网页控制台与电脑端工具集
    - firmware/commander/：主控 ESP32 Arduino 工程（差速+软启动、MPU6050
    直线保持 PID、三向超声波 AUTO-L2 避障、IDLE/AUTO/TELEOP/CAPTURE/
    E-STOP/SLEEP 状态机、热控五态机、深睡+唤醒计数+冲刺模式、UART2
    相机链路、WebSocket 遥测遥控；兼容 esp32 core 2.x/3.x）
    - firmware/cam/：ESP32-CAM 固件（拍照 HTTP 上传、/stream MJPEG、
    UART 从协议应答，无第三方库依赖）
    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
